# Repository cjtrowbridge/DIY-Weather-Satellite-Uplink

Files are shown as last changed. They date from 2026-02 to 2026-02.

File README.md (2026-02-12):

# DIY Weather Satellite Uplink: Project Overview
Hacking an old robotic RV satellite dish to access weather data from GOES West

This document describes a retrofit project that converts an RV “in‑motion” dome satellite TV dish (a small robotic parabolic reflector under a plastic radome) into a **GOES HRIT/EMWIN ground station**. The core idea is:

* Replace the Ku‑band TV feed/LNB electronics with a purpose‑built **L‑band receive feed** for **1694.1 MHz HRIT/EMWIN**.
* Put the **LNA + SAW filter** (Nooelec SAWbird GOES) as close to the feed as possible to minimize pre‑LNA coax loss.
* Optionally replace the dish’s original motor controller with an **ESP32** (or keep the existing mechanics and drive them) to automate pointing.
* Use a **Raspberry Pi** (mounted behind the reflector) to host the **RTL‑SDR**, run the demod/decoder, and publish imagery locally.

The end state is a compact, self‑contained receiver package inside the radome:

> **Helical feed → very short SMA jumper → SAWbird GOES (shielded) → coax/SMA → RTL‑SDR → USB → Raspberry Pi**

---

# Background: GOES‑18 “GOES West” and What We’re Receiving

## GOES‑18 operational role

* **GOES‑18** became the operational **GOES‑West** satellite on **Jan 4, 2023**.
* GOES‑West is stationed around **137° W longitude**.

## HRIT/EMWIN vs other GOES downlinks (high level)

GOES satellites distribute data using multiple services. For hobbyist/low‑cost reception, the key one is:

* **HRIT/EMWIN** (High Rate Information Transmission / Emergency Manager’s Weather Information Network)

HRIT/EMWIN is designed to be receivable with modest ground equipment compared to higher‑end services like **GRB** (GOES Rebroadcast). For this project we focus on **HRIT/EMWIN**.

## HRIT/EMWIN RF characteristics (what the antenna must match)

The HRIT/EMWIN L‑band downlink is characterized by:

* **Center frequency:** 1694.1 MHz
* **Data rate:** 400 kbps
* **Symbol rate:** 927 ksps
* **Modulation:** BPSK
* **Polarization:** Linear (vertical offset)

This polarization point matters: the satellite signal is **linearly polarized**, not circular. A helical antenna naturally produces circular polarization in axial mode; however, when you place a helix at the focus of a dish you can (a) accept some mismatch, (b) orient and design for best coupling, and (c) experiment with polarization conversion if needed. In practice, many successful hobbyist HRIT setups use simple feeds (including helices) with strong LNAs and careful mechanical alignment.

## Broadcast format (what the software will decode)

* The HRIT/EMWIN broadcast is formed according to the **HRIT/LRIT standard** and **CCSDS** framing conventions.
* The stream is broadcast as a continuous downlink; the receiver software demodulates BPSK, applies FEC, reconstructs files, then extracts images/products.

---

# System Architecture Summary

## Why the project is viable

At 1.694 GHz, losses in coax before the first amplifier materially hurt SNR. The primary optimization is:

* **Put the first low‑noise gain stage at the feed** (or as close as physically possible).

Your chosen LNA/filter module (Nooelec SAWbird GOES) already provides:

* A **metal enclosure** (shielding)
* Cascaded ultra‑low noise gain stages
* An integrated **SAW filter** centered near the HRIT band

That means the biggest remaining engineering concerns are:

* Mechanical: feed placement at the dish focus
* RF hygiene: cable routing, common‑mode suppression, clean power
* Control: optional repointing automation

---

# The Existing RV Dome Dish System (What It Is)

## Mechanical components

* **Plastic radome** (weather protection; not a Faraday cage)
* **Small parabolic reflector** (≈ 16" class in many RV domes; confirm with measurement)
* **Robotic pointing mechanism**: motors, gears, and position feedback (often via potentiometers)

## RF components (Ku‑band TV)

* A Ku‑band feed/LNB assembly intended for ~10–12 GHz satellite TV.
* One or more coax outputs for RV TV distribution.

## What must change

Everything Ku‑band RF becomes irrelevant for 1.694 GHz:

* Remove the Ku feed/LNB and any internal switching/power injection that served it.
* Keep and reuse: **reflector + mechanical mount points + motorized pointing platform**.

---

# Helical Antenna Design: Geometry, Modes, and Formulas

## Key parameters (pure geometry)

A helical antenna is a wire wound around an imaginary cylinder.

* **D** = helix diameter
* **C** = circumference = πD
* **S** = turn spacing (axial spacing per turn)
* **N** = number of turns
* **L** = total helix length = N·S
* **α** = pitch angle

Pitch angle relationship:

[ \tan(\alpha) = \frac{S}{C} = \frac{S}{\pi D} ]

Wire length per turn (useful for cut length):

[ \ell_{turn} = \sqrt{C^2 + S^2} ]

Total wire length:

[ \ell_{total} = N \cdot \ell_{turn} ]

## Wavelength scaling

For a frequency ( f ):

[ \lambda = \frac{c}{f} ]

For **f = 1.6941 GHz**:

* ( \lambda \approx 0.17696,m = 17.696,cm )

## Two operating regimes

### 1) Normal mode (small helix)

* Diameter and circumference are small relative to (\lambda)
* Pattern is broad; gain is low; behaves like a bent dipole.

### 2) Axial mode (classic satellite helix)

* Radiates along the helix axis
* Produces (near) **circular polarization**
* Provides gain that increases with turns

Axial mode rules of thumb:

* **Circumference:** ( C \approx \lambda )
* **Diameter:** ( D \approx \lambda/\pi )
* **Spacing:** ( S \approx 0.23\lambda;\text{to};0.27\lambda ) (often 0.25λ)
* **Pitch angle:** typically 12°–15°

## Numerical geometry at 1.6941 GHz (axial-mode baseline)

Using (\lambda \approx 17.696,cm):

* ( C \approx 17.696,cm )
* ( D = C/\pi \approx 5.63,cm = 56.3,mm )
* ( S = 0.25\lambda \approx 4.42,cm = 44.2,mm )
* ( \alpha \approx \arctan(0.25) \approx 14.0^\circ )

These are excellent “starting geometry” dimensions for a helix that behaves predictably.

## Number of turns as a feed (beamwidth vs gain)

When used as a **dish feed**, you typically want a wider pattern than a long, high‑gain helix. A short helix (1–3 turns) often works better as a feed.

A commonly used approximation for axial-mode half‑power beamwidth (HPBW):

[ \text{HPBW} \approx \frac{52}{(C/\lambda)\sqrt{N(S/\lambda)}} ;\text{degrees} ]

With (C/\lambda \approx 1) and (S/\lambda \approx 0.25):

[ \text{HPBW} \approx \frac{104}{\sqrt{N}} ]

So:

* N=1 → ~104°
* N=2 → ~74°
* N=3 → ~60°
* N=4 → ~52°

**Practical feed starting point:** **N = 2 turns**

* Height (L = N\cdot S \approx 2 \cdot 44.2,mm = 88.4,mm) (~3.5")

## Ground reference (why “multiple elements” often connect to coax shield)

A helix is an **unbalanced** radiator in most practical builds:

* Coax **center conductor** feeds the helix start
* Coax **shield** bonds to a **ground plane** / reflector / radials

Many compact L‑band helices use **3 radials** (120° apart) instead of a large disk. Those radials are tied to the **coax shield**, and they are often the “extra elements” people notice.

---

# Dish Optics: Focus, Placement, and Why Measurements Matter

To place any feed correctly, you want the feed phase center at the dish’s focal region.

## Focal length from dish diameter and depth

If you measure:

* (D) = dish diameter
* (d) = dish depth (sagitta): distance from rim plane to deepest point

Then the focal length (f) for a parabola is:

[ f = \frac{D^2}{16d} ]

This single measurement lets you:

* compute (f/D)
* estimate required feed beamwidth (illumination)
* place the feed consistently

**Action:** measure dish depth (d) and confirm dish diameter (D).

---

# New RF Receive Pipeline (Target Design)

## Hardware chain

1. **Helical feed** at the dish focus
2. **Very short SMA jumper** (as short as practical)
3. **Nooelec SAWbird GOES** (shielded enclosure)
4. SMA/coax to **RTL‑SDR**
5. **USB** to Raspberry Pi

## Powering the SAWbird

The SAWbird can be powered via:

* bias tee
* micro‑USB
* DC barrel

For low noise, prefer:

* a clean local 5V feed with filtering near the SAWbird, or
* bias tee if your SDR chain supports it cleanly.

## EMI / self-noise control (even with a shielded LNA)

A plastic radome does not block RF. The reflector helps, but you still want hygiene:

* Keep the SAWbird close to the feed; keep Pi farther away.
* Add clamp ferrites on:

  * USB cable
  * any long power lead
  * coax if it runs near digital electronics
* Provide a deliberate local RF ground reference (feed ground plane/radials), not a “floating” coax shield in space.

## Software chain (conceptual)

* SDR capture (IQ)
* BPSK demod + symbol recovery
* FEC decode
* HRIT file reconstruction
* Image/product extraction and publishing

(Exact tool choice is flexible: common approaches include goestools/xrit decoders or general satellite decoders such as SatDump.)

---

# Control System Options (Pointing)

## Option A: keep existing motors, replace controller

* Remove original control PCB.
* Drive motors with an **ESP32 + motor drivers**.
* Read position sensors (potentiometers/encoders).
* Provide a serial/API interface to the Raspberry Pi.

## Option B: direct Pi motor control (simpler but less real-time)

* Pi drives motor drivers directly.
* Pi reads sensors.
* More software complexity in Linux; may be fine if you only occasionally reposition.

## Pointing notes

* HRIT/EMWIN is geostationary: once aimed, the dish can remain fixed.
* Automation mainly helps initial acquisition and re‑acquisition.

---

# Designing the 3D‑Printed Helix Former (Cylinder with Groove)

## Design goals

* Make the helix geometry **repeatable** and resistant to bending/creep.
* Provide mounts for:

  * feedpoint SMA bulkhead (or coax pigtail strain relief)
  * ground radials / ground disk
  * SAWbird GOES enclosure
  * cable routing + ferrite placement
* Fit within the radome with adequate clearance.

## Baseline helix dimensions (from frequency)

Using f = 1.6941 GHz:

* Helix diameter: **D = 56.3 mm**
* Radius: **R = 28.15 mm**
* Spacing per turn: **S = 44.2 mm**
* Turns for dish feed start: **N = 2**
* Helix height: **H = N·S = 88.4 mm**

## Helix centerline parameterization (for CAD)

Let (t) run from (0) to (2\pi N):

[
\begin{aligned}
x(t) &= R\cos(t)\
y(t) &= R\sin(t)\
z(t) &= \frac{S}{2\pi}t
\end{aligned}
]

This curve is the **ideal centerline** of the wire.

## Groove design (printable, “foolproof” winding)

Choose a wire diameter (d_w) (example: 12–14 AWG solid copper, or similar).

Recommended groove geometry:

* Groove width: (w \approx d_w + 0.4\text{ to }0.8,mm)
* Groove depth: (h \approx 0.4\text{ to }0.6,d_w)

Add retention features:

* Small “snap tabs” or tie points every 1/2 turn
* Optional end clamps at start and top

## Former body geometry

* Outer cylinder diameter: slightly larger than helix diameter to allow a groove wall.
* A practical approach:

  * Set cylinder OD to ~60–65 mm
  * Groove centerline radius ~28.15 mm
  * Groove cut into the cylinder wall

## Feedpoint region design

At the base:

* Provide a flat mounting face for:

  * SMA bulkhead connector (preferred for repeatability)
  * or a coax pigtail with strain relief

Electrical intent:

* SMA center pin → helix start
* SMA ground → ground plane / radials

## Ground plane / radials integration

Two common printable-friendly options:

### Option 1: 3 radial slots

* Provide 3 slots spaced 120° around the base.
* Radial length target: **50–60 mm** (roughly 0.28–0.34λ)
* Optional downward angle: 10–30°

### Option 2: ground disk mount

* Provide holes for a circular metal disk (80–120 mm diameter depending on space).
* Bond disk to SMA ground.

## Mounting to the dish assembly

Because the original Ku feed block is removed, the former should include an adapter plate:

* Use the existing bolt pattern from the prior feed assembly.
* Provide:

  * through holes for screws
  * standoffs/spacers to keep the helix away from nearby metal
  * alignment features (tabs/keys) so the assembly can’t rotate inadvertently

**Important clearance guideline:** keep random metal surfaces at least ~20–35 mm away from the helix turns when possible.

## SAWbird GOES mounting

* The SAWbird already has a metal enclosure.
* Design a bracket pocket behind the feed:

  * holds the SAWbird securely
  * keeps the feed → SAWbird SMA jumper extremely short
  * provides a clean cable exit path
  * avoids putting the Raspberry Pi directly adjacent to the feed

## Cable routing and strain relief

Integrate into the print:

* a “quiet zone” channel for RF coax
* a separate “noisy zone” channel for USB/power
* tie points and strain relief for connectors
* optional pockets for clamp ferrites

## Materials and print considerations

* PLA is fine for prototyping, but a radome can heat up.
* Consider PETG/ASA for better thermal tolerance.
* Avoid thin unsupported walls; design for vibration.

## Assembly sequence (recommended)

1. Print former + adapter plate
2. Install SMA bulkhead and ground radials/disk
3. Place wire into groove and secure at start/top
4. Install SAWbird GOES behind the feed
5. Connect short SMA jumper (feed → SAWbird)
6. Route coax to RTL‑SDR; add ferrites
7. Mount RTL‑SDR and Pi farther back
8. Validate with test captures; reposition and refine

---

# Practical Notes and Risk Register

## Dish size vs recommended antenna size

Official guidance for robust HRIT/EMWIN reception often references ~1 m class antennas at low elevations. Your RV dome dish is smaller, so outcomes will depend on:

* your location in the footprint
* elevation angle to GOES‑West
* feed efficiency and alignment
* local RF noise

This project is still worth pursuing because:

* very short pre‑LNA feedline
* filtered low‑noise front end
* controlled mechanics

…but you should expect an iterative process.

## Iteration knobs

* Helix turns: N=1 vs N=2 vs N=3
* Ground radial lengths and angles
* Feed position (± a few mm)
* Cable choke placement

---

# Next Measurements Needed (to finalize the CAD)

## Measurements captured / assumptions (current hardware)

* **Dish diameter (reflector):** **13 in** (approx. 330 mm)
* **Estimated focal length (approx.):** **4.5 in** (approx. 114 mm) (informational only; primary datum is the existing tube tip)
* **Radome headroom (assumed):** **~1–2 in** above the intended feed reference point (we will design to fit within this without requiring an exact measurement for the first iteration)
* **Plastic tube (measured):**
  * **Outer diameter (OD):** **33 mm**
  * **Length (metal post top → tube tip):** **33 mm**
  * **Feed reference datum:** the **tube tip** is treated as the **focal-point reference** for the first iteration

## Old Ku feed assembly (what’s there today)

The original Ku feed stack appears to be a bonded/glued assembly:

* **Metal post/tube** (lower): structural mount + hollow path down into the mechanism (this will be reused as a conduit)
* **Plastic tube section** (middle): bonded to the metal post/tube
* **Metal reflector/cap** (top): bonded to the plastic tube

## Revised mechanical plan (preserve focus datum, replace tube interface)

The project's mechanical reference is still the same:

* **Focus datum:** the original **plastic tube tip position** (CAD: **`z=0`**)
* **Mount seat plane:** the **metal post top** (CAD: **`z=-33mm`**)

All feed prototypes are designed so the **driven element / feed reference** is at **`z=0`**, and the mount interfaces to the dish at **`z=-33mm`**.

### Shared mount interface (new)

Instead of printing parts that slip *over* the old plastic tube, we print a short **33mm OD mount stub** near the seat plane:

* The stub is **hollow** so an SMA pigtail can route down the metal shaft.
* The stub length is intentionally short (insertion length is not critical); the critical invariant is keeping **`z=0`** at the original focus datum.

### Helical prototype: thin-wall former + mount stub (no grooves yet)

* Part: `helical_former` (OpenSCAD: `cad/designs/helical/src/parts/helical_former.scad`)
* A thin-walled clearance cylinder (~60mm OD) above a short 33mm OD mount stub.
* Future iterations add helix grooves + retention features sized to the chosen wire diameter.

### Yagi prototype: 3-element center-driven dipole yagi + mount stub

* Part: `yagi_mount` (OpenSCAD: `cad/designs/yagi/src/parts/yagi_mount.scad`)
* Prints a backplane/boom with **partial-depth grooves** for **~6mm^2 solid copper** elements (glue-in).
  * Grooves are sized so the wire is **fully recessed** (does not protrude above the card face).
  * Grooves are positioned so the wire **centerline aligns with the mount stub axis** (CAD: **`y=0`**).
  * Grooves do **not** cut through the card thickness; a **back wall remains** for strength + glue surface.
  * Each groove length is the element length plus **+1mm margin on each end** (wire still must be cut to the exact RF length).
  * Element wire lengths are **RF-critical**; cut elements to the exact lengths below.
* Element layout (center-to-center spacing **22mm** along the dish axis):
  * **Director/front:** **66mm** at **`z=-22mm`**
  * **Driven dipole:** **83mm** at **`z=0mm`** (includes a center cutout for feedpoint separation + coax exit)
  * **Reflector/rear:** **87mm** at **`z=+22mm`**

### Yagi card-only prototype: element backplane only (no stub/plug)

* Part: `yagi_card` (OpenSCAD: `cad/designs/yagi_card/src/parts/yagi_card.scad`)
* Prints only the backplane/boom + grooves (same element layout as `yagi_mount`) for rapid fit checks and element placement without committing to the mount stub geometry.
* By default the card is positioned to match the mounted yagi (`card_bottom_z = -mount_seat_to_focus + 6mm`), so the driven element stays at `z=0` when the card is later paired with a separate plug/stub.

## Still needed before printing final-fit parts

For first-pass prototypes we are explicitly proceeding with the assumptions above. These are only needed for final, repeatable, dimension-locked prints:

1. **Radome clearance (hard number):** maximize performance without risking interference with the dome.
2. **Helical wire diameter (final):** size grooves/retention features appropriately.
3. **Dish mount interface tolerances:** confirm the holder/socket geometry so the 33mm mount stub can be dimensioned with appropriate clearance and retention.

Once these are known, the printable mount + feed geometry can be locked down for a repeatable build.

---

# OpenSCAD Prototyping Pipeline (Local)

This repo uses a simple, local OpenSCAD workflow (no CI) to iterate on the feed + mount geometry and snapshot numbered revisions as the design evolves.

## Folder layout

* `cad/designs/<design>/src/` - OpenSCAD source for a design (`main.scad` entrypoint + `parts/` + `lib/`)
* `cad/designs/<design>/configs/` - Parameter sets (JSON) for specific revisions (committed)
* `cad/revisions/<design>/` - Local revision snapshot outputs (generated; ignored by git)
* `cad/out/<design>/` - Scratch build outputs (generated; ignored by git)
* `scripts/` - PowerShell helpers for building and creating revisions

## Prerequisites

* OpenSCAD installed locally and `openscad` available on your `PATH`.
* Note: configs use a numeric `part_id` for part selection (Windows `-D` string quoting is fragile).

## Common commands

* Build a part to scratch output:
  * Helical example:
    * `powershell -ExecutionPolicy Bypass -File scripts/scad_build.ps1 -Design helical -Config cad/designs/helical/configs/rev_0003.json`
  * Yagi example:
    * `powershell -ExecutionPolicy Bypass -File scripts/scad_build.ps1 -Design yagi -Config cad/designs/yagi/configs/rev_0002.json`
  * Yagi card-only example:
    * `powershell -ExecutionPolicy Bypass -File scripts/scad_build.ps1 -Design yagi_card -Config cad/designs/yagi_card/configs/rev_0001.json`
  * If `openscad` is not on `PATH`, pass `-OpenScadPath` (recommended on Windows):
    * `powershell -ExecutionPolicy Bypass -File scripts/scad_build.ps1 -Design helical -Config cad/designs/helical/configs/rev_0003.json -OpenScadPath "C:\Program Files (x86)\OpenSCAD\openscad.exe"`
* Snapshot a new numbered revision for a design (creates `cad/revisions/<design>/rev_000N/` and `cad/designs/<design>/configs/rev_000N.json`):
  * `powershell -ExecutionPolicy Bypass -File scripts/scad_new_revision.ps1 -Design helical -BaseConfig cad/designs/helical/configs/rev_0003.json`
  * With explicit OpenSCAD path:
    * `powershell -ExecutionPolicy Bypass -File scripts/scad_new_revision.ps1 -Design helical -BaseConfig cad/designs/helical/configs/rev_0003.json -OpenScadPath "C:\Program Files (x86)\OpenSCAD\openscad.exe"`

See `playbooks/how_to_iterate_openscad_designs.md` for the full workflow.

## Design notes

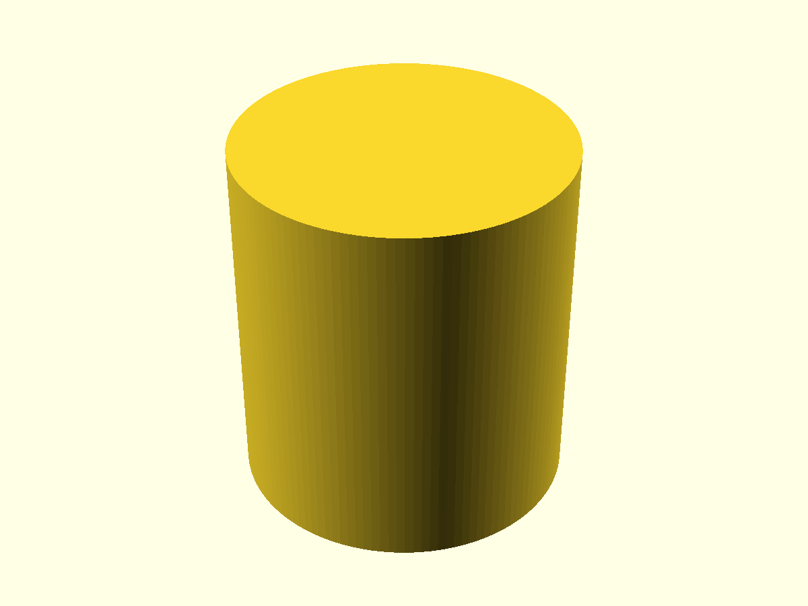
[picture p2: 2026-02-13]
cad/out/fit_sleeve.png

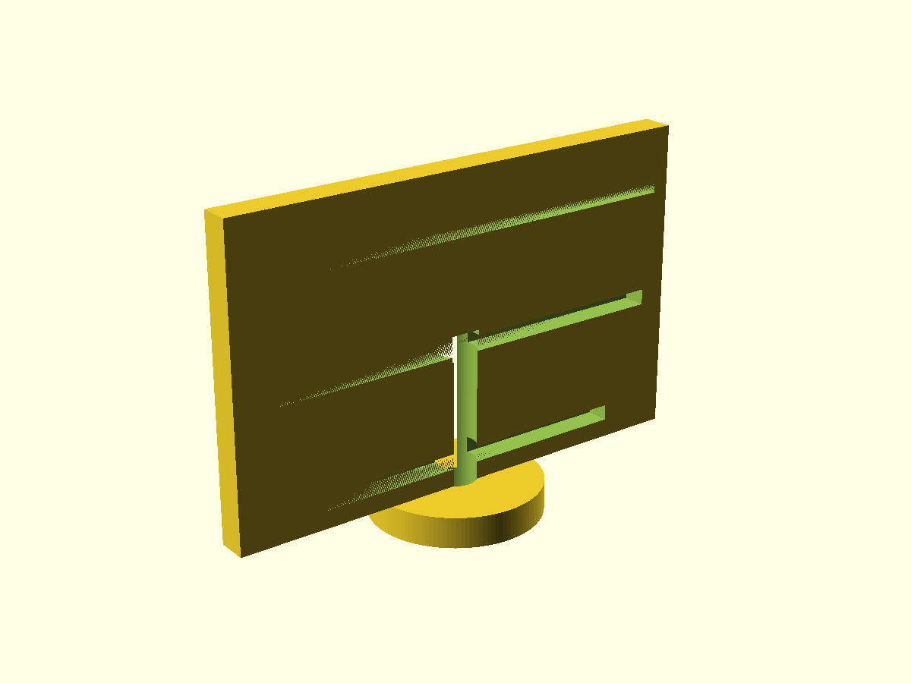
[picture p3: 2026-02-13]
cad/out/yagi/yagi_mount_grooves_view.png

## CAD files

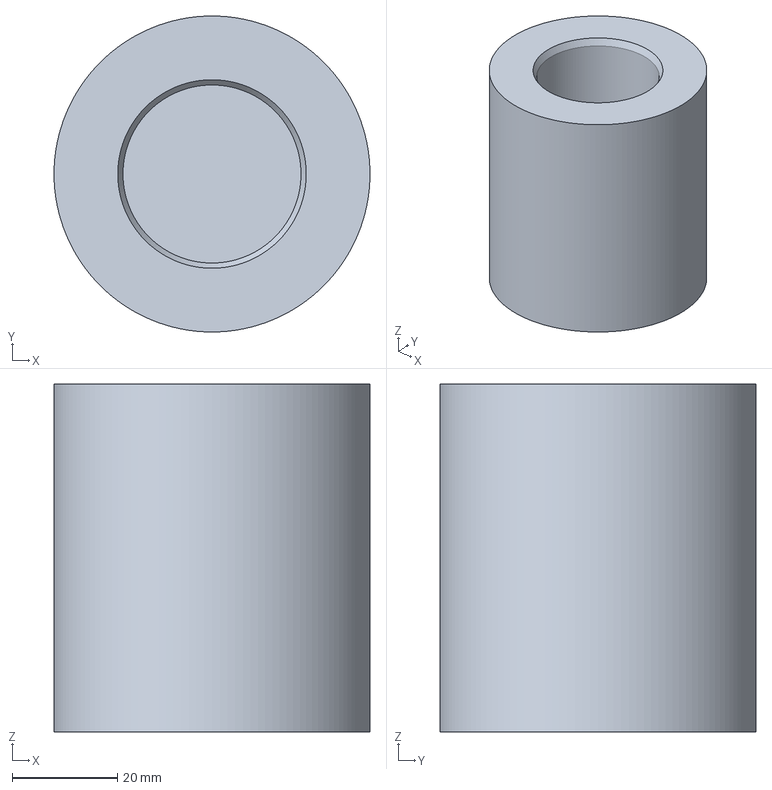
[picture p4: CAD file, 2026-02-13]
cad/out/fit_sleeve.3mf
60.0 x 60.0 x 66.0 mm

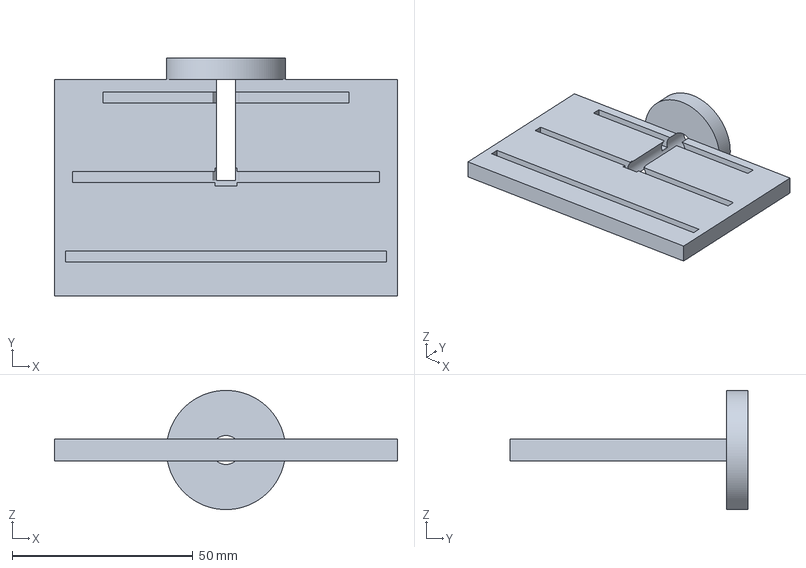
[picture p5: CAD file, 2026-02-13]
cad/out/yagi/yagi_mount.3mf
95.0 x 66.0 x 33.0 mm

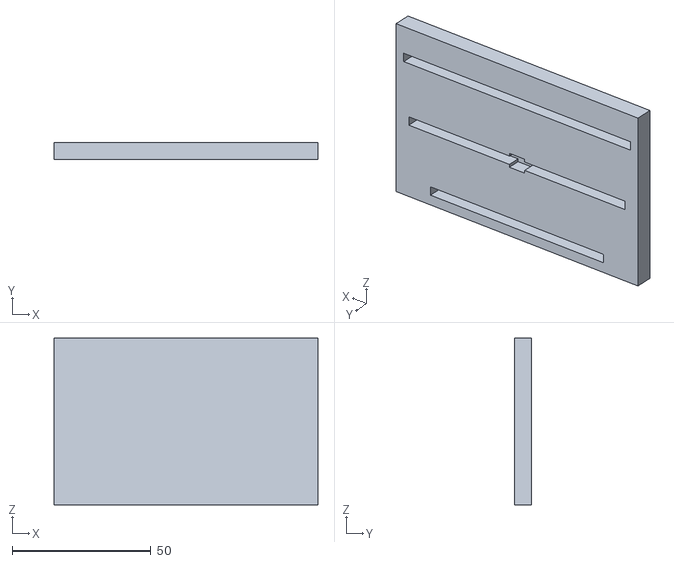
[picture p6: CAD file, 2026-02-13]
cad/out/yagi_card/yagi_card.stl
95.0 x 6.00 x 60.0

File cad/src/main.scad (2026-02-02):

// Entry point for scripted exports.
// Usage:
//   openscad -o out.stl cad/src/main.scad -D part_id=0 -D post_od=45 ...

include <lib/defaults.scad>;
include <parts/feed_mount.scad>;
include <parts/fit_sleeve.scad>;

_part_id = is_undef(part_id) ? 0 : part_id;

if (_part_id == 0) {
  feed_mount();
} else if (_part_id == 1) {
  fit_sleeve();
} else {
  assert(false, str("Unknown part_id: ", _part_id));
}

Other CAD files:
cad/designs/helical/src/main.scad
cad/designs/yagi/src/main.scad
cad/designs/yagi_card/src/main.scad
cad/designs/helical/src/parts/feed_mount.scad
cad/designs/helical/src/parts/helical_former.scad
cad/designs/yagi/src/parts/yagi_mount.scad
cad/designs/yagi_card/src/parts/yagi_card.scad
cad/out/fit_sleeve.stl
cad/out/yagi/yagi_mount.stl

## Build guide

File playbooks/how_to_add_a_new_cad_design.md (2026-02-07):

# Playbook: How to Add a New CAD Design

*Status: Draft*

## Objective
Add a new OpenSCAD design under `cad/designs/<design>/` with its own source tree and configs, while preserving the project's shared focus datum conventions and keeping documentation consistent.

## Prerequisites
* OpenSCAD installed locally (Windows).
* Either:
  * `openscad` available on `PATH`, or
  * provide the full path to `openscad.exe` via `-OpenScadPath`.
* Run commands from the repository root: `c:\Users\CJ\Documents\GitHub\DIY-Weather-Satellite-Uplink`.

## Step-by-Step Instructions

1. **Choose a design name**
   * Pick a short, descriptive folder name for `<design>` (e.g., `helical`, `yagi`).

2. **Preserve the shared mechanical datum**
   * All designs should use the same coordinate convention:
     * `z=0` is the **focus datum** (original plastic tube tip position).
     * The **mount seat plane** (metal post top) is at `z=-mount_seat_to_focus` (default `33mm`).
   * Any new design should explicitly document this in its `defaults.scad` and/or part modules.

3. **Create the design folder layout**
   * Create:
     * `cad/designs/<design>/src/main.scad`
     * `cad/designs/<design>/src/lib/defaults.scad`
     * `cad/designs/<design>/src/parts/<part>.scad`
     * `cad/designs/<design>/configs/rev_0001.json`
   * Keep `main.scad` as the scripted export entrypoint that selects a part via numeric `part_id`.

4. **Add at least one config**
   * Create `cad/designs/<design>/configs/rev_0001.json` with:
     * `part_id` (numeric) and an optional `part` string (used for output naming).
     * Any parameters needed by the design's `defaults.scad` / part modules.
   * Prefer numeric `part_id` (Windows `-D` string quoting is fragile).

5. **Update documentation**
   * Update `README.md`:
     * Add/adjust the OpenSCAD folder layout (multi-design structure).
     * Add the new design description and its invariants (especially the focus datum).
     * Add example build commands for the new design.
   * If the workflow changed, update `playbooks/how_to_iterate_openscad_designs.md`.
   * If you added/removed playbooks, update `AGENTS.md` playbook index.

6. **Verify**
   * Run a DryRun build (does not require OpenSCAD):
     * `powershell -ExecutionPolicy Bypass -File scripts/scad_build.ps1 -Design <design> -Config cad/designs/<design>/configs/rev_0001.json -DryRun`

7. **Finalize**
   * Follow `playbooks/how_to_commit_and_push_changes.md`:
     * review `git status -sb`
     * review diffs
     * propose commit message
     * commit only after explicit approval

## Verification
* `scripts/scad_build.ps1 -DryRun` resolves `MainScad` and prints both intended OpenSCAD commands without error.
* `README.md` and relevant playbooks reflect the new design and folder layout.

## Lifecycle Compliance
Prompt -> Plan (based on a known playbook) -> Request approval -> Execute -> Plan/playbook update -> Docs update -> Verification.

If inside a git repo:
* Review `git status -sb` and diffs.
* Suggest a commit message.
* Commit after completion.

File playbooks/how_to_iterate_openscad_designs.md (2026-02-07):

# Playbook: How to Iterate OpenSCAD Designs

*Status: Draft*

## Objective
Provide a repeatable local workflow to iterate OpenSCAD (`.scad`) prototypes, generate preview images and STL exports, and snapshot numbered design revisions with their parameter sets.

## Prerequisites
* OpenSCAD installed locally (Windows).
* Either:
  * `openscad` available on `PATH`, or
  * provide the full path to `openscad.exe` via `-OpenScadPath` (recommended; avoids PATH edits).
* Run commands from the repository root: `c:\Users\CJ\Documents\GitHub\DIY-Weather-Satellite-Uplink`.

## Step-by-Step Instructions

This repo follows an explicit iteration loop:

1. **Create a new revision folder (checkpoint)**
   * Start each chunk of work by snapshotting a new revision folder so you have a stable baseline to compare against.
   * Command (example):
     * `powershell -ExecutionPolicy Bypass -File scripts/scad_new_revision.ps1 -Design helical -BaseConfig cad/designs/helical/configs/rev_0003.json -OpenScadPath "C:\Program Files (x86)\OpenSCAD\openscad.exe"`
   * Expected:
     * A new folder like `cad/revisions/helical/rev_0002/`
     * `cad/revisions/helical/rev_0002/params.json`
     * `cad/revisions/helical/rev_0002/<part>.stl` and `<part>.png` (if OpenSCAD is available)

2. **Implement the specified design changes**
   * Edit `.scad` modules under `cad/designs/<design>/src/` (or configs under `cad/designs/<design>/configs/`) according to the requested change.

3. **Loop: build artifacts -> ask for feedback -> revise**
   1) Build outputs (scratch build to `cad/out/<design>/`):
      * `powershell -ExecutionPolicy Bypass -File scripts/scad_build.ps1 -Design helical -Config cad/designs/helical/configs/rev_0003.json -OpenScadPath "C:\Program Files (x86)\OpenSCAD\openscad.exe"`
   2) Ask the user to test/inspect results and provide feedback.
   3) Apply feedback and repeat Step 3 until the user is satisfied.

4. **Finalize and commit**
   * Follow `playbooks/how_to_commit_and_push_changes.md`:
     * review `git status -sb`
     * review diffs
     * propose commit message
     * commit only after explicit approval

## Notes
* Parameter files live in `cad/designs/<design>/configs/` (e.g., `cad/designs/helical/configs/rev_0003.json`).
* Configs should include a numeric `part_id` (Windows `-D` string quoting is fragile). The human-readable `part` field is optional/for convenience.
* Scratch outputs go into `cad/out/<design>/` (ignored by git).
* Revision outputs go into `cad/revisions/<design>/rev_000N/` (ignored by git); only `.scad` source and `cad/designs/<design>/configs/*.json` are committed.

## Verification
* Run a scratch build and confirm both `.stl` and `.png` are produced in `cad/out/<design>/`.
* Create a new revision snapshot and confirm a new revision folder contains `params.json`, `.stl`, and `.png`.

## Lifecycle Compliance
Prompt -> Plan (based on a known playbook) -> Request approval -> Execute -> Plan/playbook update -> Docs update -> Verification.

If inside a git repo:
* Review `git status -sb` and diffs.
* Suggest a commit message.
* Commit after completion (per `playbooks/how_to_commit_and_push_changes.md`).

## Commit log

2026-02-02 created scad pipeline
    [feed_mount.scad, main.scad]
2026-02-02 Add fit_sleeve prototype and improve OpenSCAD workflow
    [fit_sleeve.scad, main.scad]
2026-02-07 Refactor CAD into cad/designs; add yagi mount prototype
    [feed_mount.scad, fit_sleeve.scad, helical_former.scad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]
2026-02-07 added new yagi design
    [yagi_mount.scad]
2026-02-12 added simplified yagi card
    [main.scad, yagi_card.scad]
2026-02-13 idk why artefacts were ignored. this is what the people want!
    [fit_sleeve.3mf, fit_sleeve.stl, yagi_card.stl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]
